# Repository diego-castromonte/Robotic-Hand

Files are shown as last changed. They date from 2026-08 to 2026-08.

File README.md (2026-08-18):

# 6-DOF Robotic Hand with Rotating Base

A custom 3D-printed 6 Degree-of-Freedom (DOF) robotic hand project controlled by an Arduino Uno, custom PCB shield, micro servos, and a 28BYJ-48 stepper motor base assembly.

---

## Overview

This project features an **Arduino Uno Shield PCB** designed in KiCad to route dedicated power to actuators and test multi-servo control alongside stepper base rotation. It supports dual control via onboard potentiometers and USB Serial commands.

*Note: The PCB design has passed KiCad ERC/DRC checks, but physical board fabrication and hardware verification are currently pending.*

### Key Features
* **Hand Actuation:** Individual finger actuation + wrist/palm tilt servo.
* **Base Rotation:** Driven by a 28BYJ-48 stepper motor via an integrated ULN2003 driver interface.
* **Custom PCB Shield:** Integrates external DC power terminals, 3-pin servo headers, stepper outputs, and 3 control potentiometers onto an Arduino shield.
* **Control Modes:** Manual potentiometer positioning alongside a 115200 baud UART Serial Command Interface (`1o`/`1c` through `5o`/`5c`, `R`).

---

## Known Issues & Current Limitations

This build is an active prototype with several physical and mechanical limitations:

* **Finger Stuttering:** Jitter or stuttering occurs during finger motion due to power distribution noise and line friction.
* **Servo Mount Placement:** The physical servo mounting bracket is currently a prototype iteration and requires CAD dimensional adjustments for better alignment.
* **Tendons & Return Mechanism (Single-Line Cable Setup):** Fingers are pulled closed using a fishing line tendon routed to the servo and returned using elastic bands. Because of this tension mechanism, finger movement is not fully independent or rigid.
* **Future Mechanism Upgrade:** The mechanical setup is planned to be updated to a direct antagonist/pulley assembly (where dynamic 0° to 180° rotation directly pulls the finger closed, and reversing the rotation drives the joint fully open).

---

## Repository Structure

* **CAD/** — 3D Printable STL Files (`All_Fingers.stl`, `Hand_Palm.stl`, `servo_mount.stl`, etc.)
* **Firmware/** — Arduino MCU C++ Code (`Hand_Code_Final.ino`)
* **PCB/** — KiCad PCB Files, Schematics & Renders (`Hand_gerbers.zip`, `Robotic_HAND.png`, `Robotic_HAND_schematic.svg`)
* **LICENSE**
* **README.md**

---

## Hardware & Bill of Materials 

### Electronics & Components
| Component | Quantity | Connection / Function |
| :--- | :--- | :--- |
| **Arduino Uno R3** | 1 | Primary Microcontroller |
| **Micro Servos (SG90 / MG90S)** | 6 | Pins 2–7 (Pinky, Ring, Middle, Index, Thumb, Palm) |
| **28BYJ-48 Stepper Motor** | 1 | Pins 8, 9, 10, 11 (Base Rotation) |
| **ULN2003 Driver Module** | 1 | Connects to `ULN2003_J1` & `JULNpwr_J2` PCB headers |
| **Trimmer Potentiometers** | 3 | Onboard inputs `RV1` (A0), `RV2` (A1), `RV3` (A2) |
| **2-Pin Screw Terminal (`J1`)** | 1 | Dedicated external DC supply input for actuators |
| **Custom Arduino Shield PCB** | 1 | Custom 2-layer power & signal routing PCB |
| **Pin Headers (Male & Female)** | Assorted | Component, servo, and Arduino connections |
| **Fishing Line (Monofilament)** | Spool | Tension cable for flexion pulling mechanism |
| **Elastic Bands** | Assorted | Passive return tension for finger extension |

---

## Hardware Schematics & PCB Design

The custom shield routes actuator power (`+5V_MOTOR`) separately from the logic supply to avoid microcontroller reset loops during multi-servo movement.

### Schematic
Custom Shield Schematic

### Board Layout & 3D Renders
| Isometric View | Top View |
| :---: | :---: |
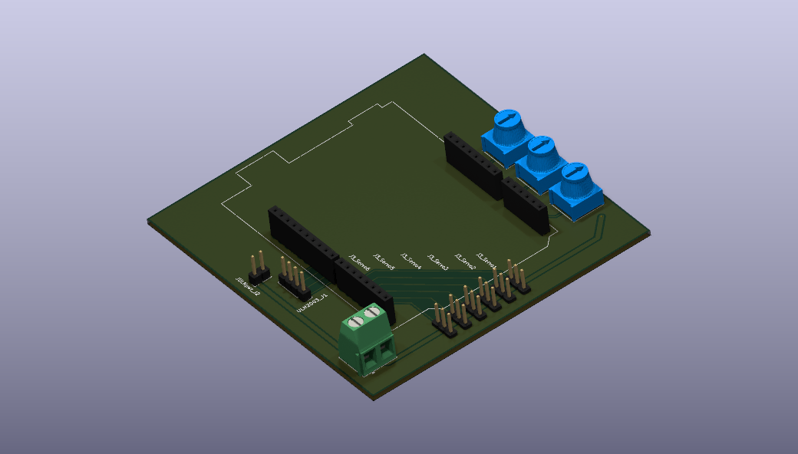
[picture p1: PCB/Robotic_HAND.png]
Isometric Render
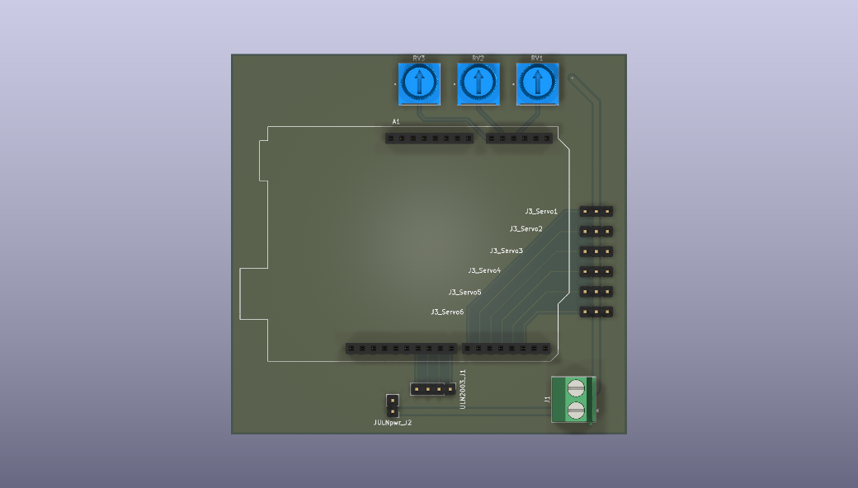
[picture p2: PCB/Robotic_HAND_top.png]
Top Render
|  |  |

---

## Software & Control Logic

The primary controller code is located at `/Firmware/Hand_Code_Final.ino`.

### Serial Commands (115200 Baud)

Open the Arduino Serial Monitor at **115200 baud** to issue positional commands:

| Command | Action | Command | Action |
| :--- | :--- | :--- | :--- |
| `1o` / `1c` | Pinky Open / Close | `4o` / `4c` | Index Open / Close |
| `2o` / `2c` | Ring Open / Close | `5o` / `5c` | Thumb Open / Close |
| `3o` / `3c` | Middle Open / Close | `R` or `r` | **Reset All** (All servos to default) |

---

## Getting Started

1. **Assemble Hardware:** Print the components from `/CAD` and mount the custom PCB shield onto your Arduino Uno.
2. **Power Supply:** Connect an external 5V 2A DC power source to terminal block `J1` to power the servos separately.
3. **Upload Firmware:** Open `/Firmware/Hand_Code_Final.ino` in the Arduino IDE, select **Arduino Uno**, choose your COM port, and click **Upload**.

---

## License

Distributed under the MIT License. See `LICENSE` for details.

## Acknowledgements & Credits

* **Hand, Fingers & Forearm CAD:** Derived from the open-source [Humanoid Robotic Hand](https://www.thingiverse.com/thing:2269115) project by **grossrc** on Thingiverse (April 2017).
* **Custom Engineering & Modifications:** Designed the 3D-printed rotating base assembly, custom servo mounting brackets, firmware control algorithms, and the KiCad Arduino shield PCB.

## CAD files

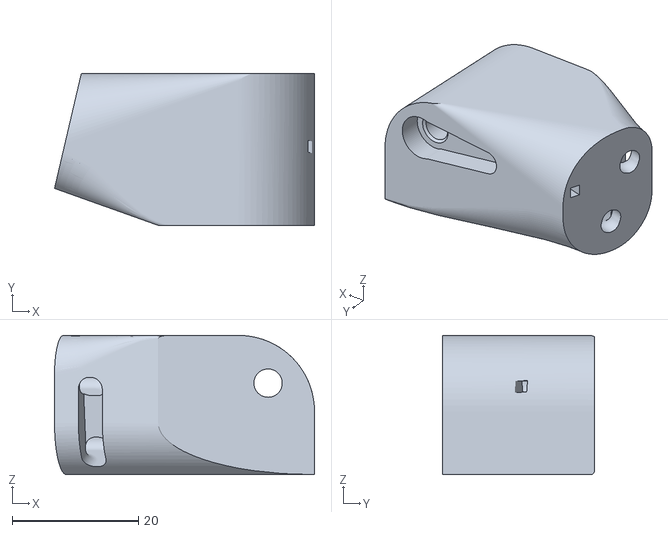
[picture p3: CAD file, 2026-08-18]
CAD/Thumb.stl
41.1 x 24.0 x 22.0

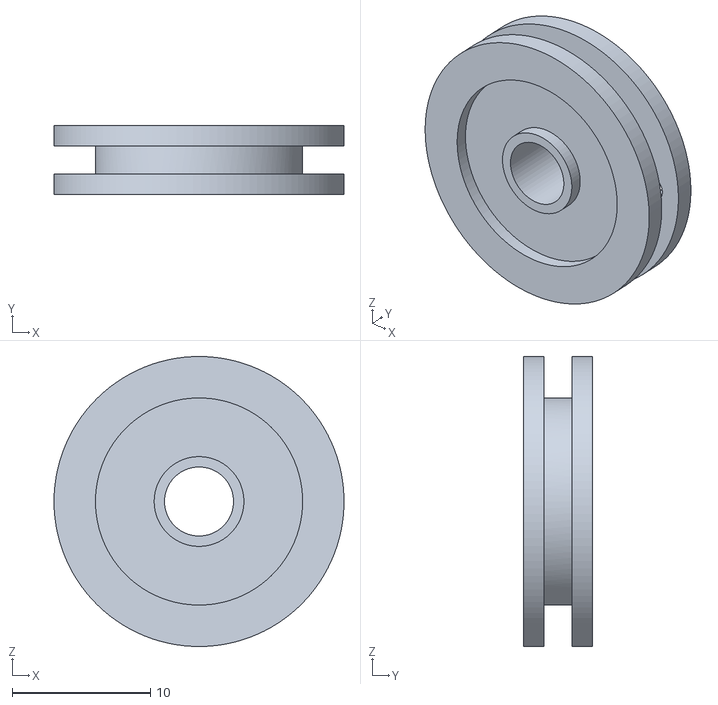
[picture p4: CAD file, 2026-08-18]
CAD/servo_pull_atch.stl
21.0 x 5.00 x 21.0

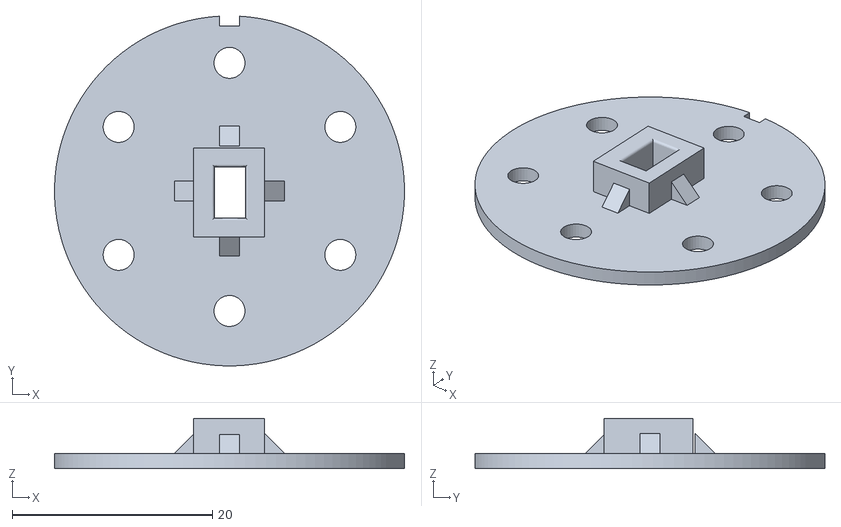
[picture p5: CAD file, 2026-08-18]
CAD/Stepper_base_atch.stl
35.0 x 35.0 x 5.00

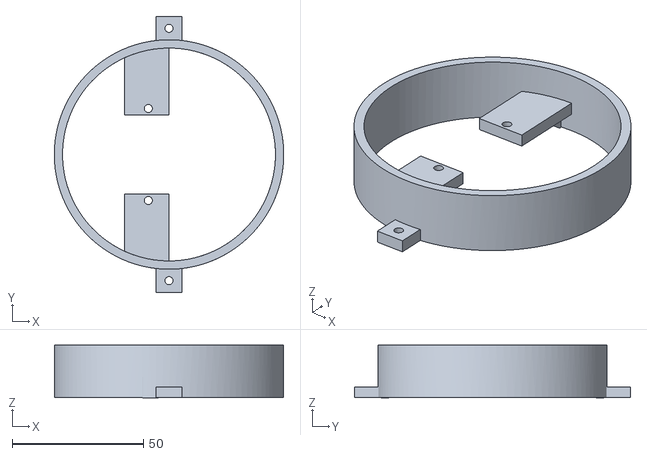
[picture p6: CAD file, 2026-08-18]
CAD/Arm_Base_top.stl
87.3 x 105.0 x 20.0

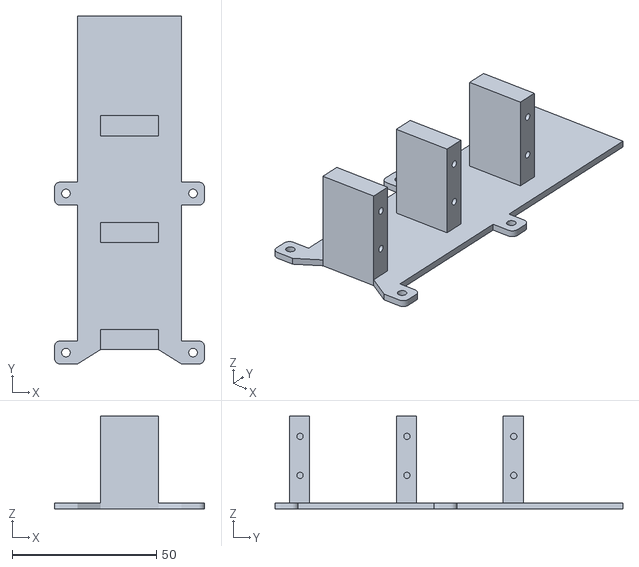
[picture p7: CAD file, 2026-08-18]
CAD/servo_mount.stl
52.0 x 120.5 x 32.1

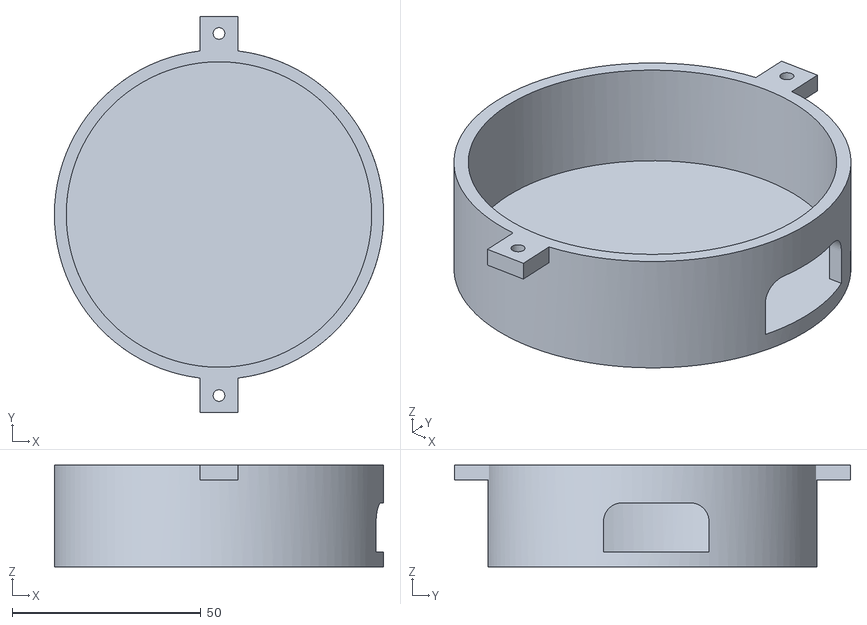
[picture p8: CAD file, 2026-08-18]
CAD/Arm_Base_bottom.stl
87.3 x 105.0 x 27.0

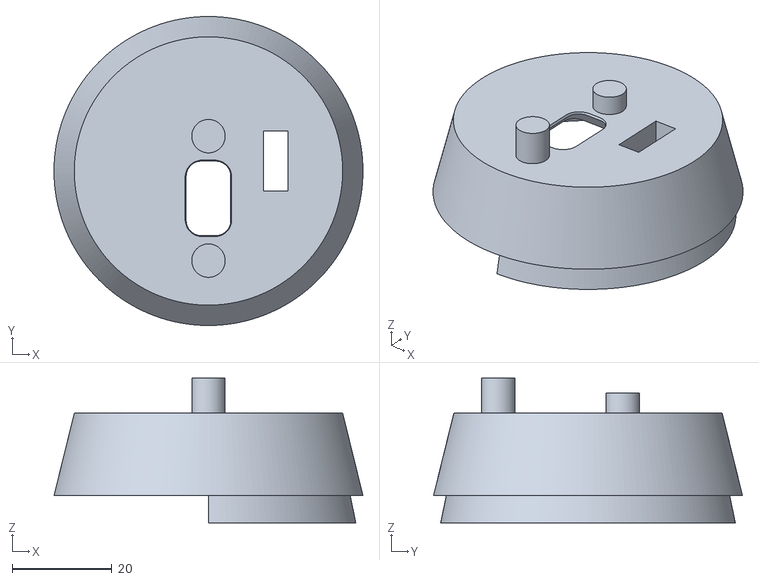
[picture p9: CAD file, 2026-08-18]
CAD/forarm_top.stl
62.1 x 62.1 x 29.1

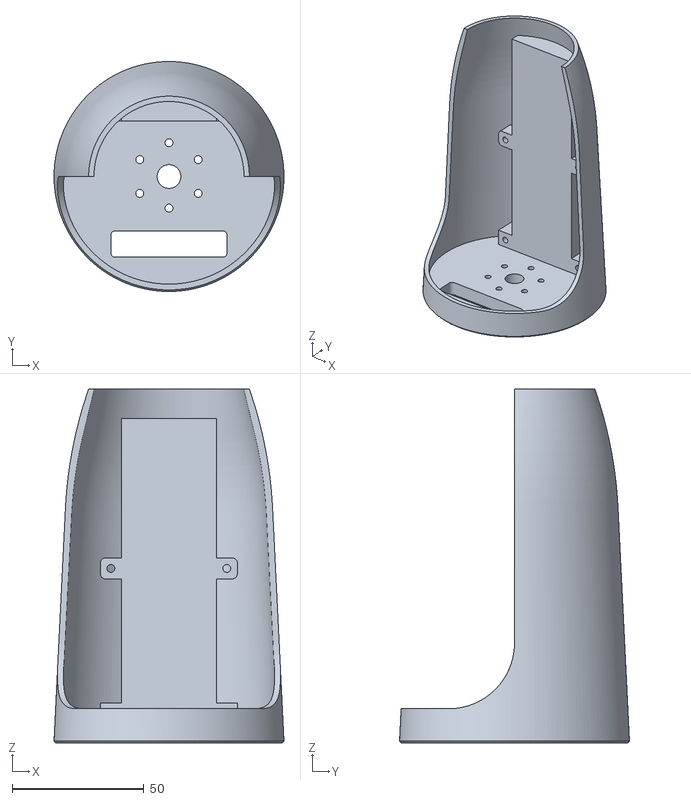
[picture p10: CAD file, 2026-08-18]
CAD/forarm.stl
87.3 x 87.3 x 134.4

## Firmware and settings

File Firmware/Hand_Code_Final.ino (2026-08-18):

#include <Stepper.h>
#include <Servo.h>

Servo pinky, ring, middle, index, thumb, palm;

// Hand pins 
const int PinkyPin = 7;
const int RingPin = 6;
const int MiddlePin = 5;
const int IndexPin = 4;
const int ThumbPin = 3;
const int PalmPin = 2;

// Rotation Base
const int potPin = A0; 
const int StepsPerRevolution = 2048;
const int rpm = 10;
Stepper myStepper(StepsPerRevolution, 8, 10, 9, 11);
int previousVal = 0; 

// Servo Palm
const int PalmPotPin = A1; 
int previousPalmVal = -1;

// Fingers Potentiometer 
const int HandPotPin = A2;
int previousHandVal = -1;

void resetAll() {
  pinky.write(180);
  ring.write(180);
  middle.write(180);
  index.write(180);
  palm.write(180);
  thumb.write(180);
  Serial.println("All reset");
}

void setup() {
  Serial.begin(115200);
  myStepper.setSpeed(rpm);

  pinky.attach(PinkyPin);
  ring.attach(RingPin);
  middle.attach(MiddlePin);
  index.attach(IndexPin);
  palm.attach(PalmPin);
  thumb.attach(ThumbPin);

  resetAll();
  
  // Initialize baseline analog readings
  previousVal = analogRead(potPin);
  previousPalmVal = map(analogRead(PalmPotPin), 0, 1023, 0, 180);
  previousHandVal = map(analogRead(HandPotPin), 0, 1023, 0, 180);
}

void loop() {
  // 1. Base Stepper Rotation (Incremental movement)
  int currentVal = analogRead(potPin);
  int diff = currentVal - previousVal;
  if (abs(diff) > 5) { // Small noise deadband
    myStepper.step(diff > 0 ? 2 : -2); // Incremental steps to prevent blocking
    previousVal += (diff > 0 ? 2 : -2);
  }

  // 2. Palm Servo (Only updates if knob is actively turned)
  int palmRaw = analogRead(PalmPotPin);
  int currentPalmVal = map(palmRaw, 0, 1023, 0, 180);
  if (abs(currentPalmVal - previousPalmVal) > 2) {
    palm.write(currentPalmVal);
    previousPalmVal = currentPalmVal;
  }

  // 3. Serial Keyboard Commands
  if (Serial.available()) {
    String cmd = Serial.readStringUntil('\n');
    cmd.trim();

    if      (cmd == "1o") { pinky.write(0); }
    else if (cmd == "1c") { pinky.write(180); }
    else if (cmd == "2o") { ring.write(0); }
    else if (cmd == "2c") { ring.write(180); }
    else if (cmd == "3c") { middle.write(180); }
    else if (cmd == "3o") { middle.write(0); }
    else if (cmd == "4c") { index.write(180); }
    else if (cmd == "4o") { index.write(0); }
    else if (cmd == "5o") { thumb.write(180); }
    else if (cmd == "5c") { thumb.write(0); }
    else if (cmd == "R" || cmd == "r") { resetAll(); }
    else { Serial.println("Invalid Command"); }
  }

  // 4. Hand Potentiometer (Only overrides servos if knob is actively rotated)
  int handRaw = analogRead(HandPotPin);
  int currentHandVal = map(handRaw, 0, 1023, 0, 180);
  if (abs(currentHandVal - previousHandVal) > 2) {
    pinky.write(currentHandVal);
    ring.write(currentHandVal);
    middle.write(currentHandVal);
    index.write(currentHandVal);
    thumb.write(180 - currentHandVal);
    previousHandVal = currentHandVal;
  }

  delay(5);
}

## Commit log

2026-08-18 Create Gerber
2026-08-18 Create ArduinoIDE
2026-08-18 Create Arduino
